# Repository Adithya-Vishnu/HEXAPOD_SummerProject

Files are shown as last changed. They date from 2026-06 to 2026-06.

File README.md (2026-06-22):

# 🦿 HEXAPOD — IITK Robotics Club Summer Project 2025








A from-scratch **18-DOF, six-legged walking robot** — custom CAD, inverse/forward kinematics, Euler-Lagrange dynamics, gait generation, and a Teensy 4.1-driven control stack, built end-to-end over Summer 2025 under the **Robotics Club, IIT Kanpur**.

<p align="center">
  <i>Six legs · three joints each · one base · zero off-the-shelf kits.</i>
</p>

---

## 📌 Overview

Hexapod robots trade the simplicity of wheels for the ability to walk over rubble, gaps, and uneven ground — at the cost of having to solve 18 coupled joint angles in real time just to take a step. This project builds that stack from the ground up:

- **Mechanical** — a hexagonal, circularly-symmetric chassis with slide-in, swappable legs
- **Kinematics** — closed-form inverse kinematics per leg, derived and verified in Python
- **Dynamics** — joint torques derived symbolically via the Euler-Lagrange method (SymPy)
- **Control** — three control-architecture iterations, ending on a single Teensy 4.1 driving all 18 servos directly
- **Locomotion** — wave, ripple, and tripod gaits, simulated in MATLAB before deployment
- **Interface** — manual RC joystick control mapped to omnidirectional leg-sector navigation

Full technical writeup: **[`Hexapod_Documentation.pdf`](./Hexapod_Documentation.pdf)** · Final review deck: **[`End-Eval_Presentation.pdf`](./End-Eval_Presentation.pdf)**

---

## ✨ Highlights

| | |
|---|---|
| **Degrees of Freedom** | 18 (6 legs × 3 DOF: coxa / femur / tibia) |
| **Base** | Hexagonal, legs at edge-midpoints for max clearance + load symmetry |
| **Leg joints** | Dual-bearing supported, slide-lock mounted, fully swappable |
| **Actuation** | 18 × DS5160 60 kg·cm metal-gear digital servos |
| **Controller** | Teensy 4.1 (600 MHz ARM Cortex-M7) — direct PWM, no multiplexing |
| **Power** | 2S1P 7.4V LiPo, 3300 mAh, 25C, XT60 |
| **Gaits** | Wave · Ripple · Tripod — all simulated in MATLAB |
| **Control input** | FlySky FS-i6 RC transmitter, atan2-based 6-sector direction mapping |

---

## 📂 Repository Structure

```
HEXAPOD_SummerProject/
├── CAD_Design/              # Fusion 360 source + STEP exports for every part
│   ├── Assembled bot.f3z        — full bot assembly
│   ├── Entire_BODY v4.f3z        — body/base iteration
│   ├── fixed_tibia.f3d           — tibia (cross-braced, lightweight)
│   ├── hexapod_coxa and slidder.step
│   ├── slider mount.step
│   └── Coxa servo motor.SLDPRT / .STEP
│
├── Codes/                   # Firmware, kinematics, and gait code
│   ├── Teensy_code.ino           — single-board 18-servo control (final arch.)
│   ├── 3_GAITS.ino               — wave / ripple / tripod gait state machine
│   ├── hexapod_ik_solution.py    — inverse kinematics solver per leg
│   ├── Forward kinematics.py     — FK verification against IK output
│   ├── Ripple.m.txt              — MATLAB ripple gait simulation
│   └── Code.cpp                  — leg-position / coordinate transform math
│
├── Entry tasks/              # Onboarding tasks completed before the main build
│   (DOF visualizations, early IK attempts, trig derivations)
│
├── Gcodes/                   # Sliced G-code for every 3D-printed part
│
├── timelapse/                 # Build-process videos, print timelapses
│
├── Hexapod_Documentation.pdf   # Full technical report (mechanical + electrical + control)
└── End-Eval_Presentation.pdf   # Final evaluation slide deck
```

---

## 🦾 Mechanical Design

- **Hexagonal base** chosen over circular for the same structural symmetry at lower material cost; legs sit at **edge midpoints** rather than corners for better clearance and base-leg contact area.
- Each leg **slides into the base** through interlocking stepped slots — this maximizes coxa-base contact area (the coxa sees the highest torque in the system) and lets a faulty leg be swapped without touching the rest of the bot.
- The **coxa-femur joint** went through a full redesign cycle: an initial plus-shaped cross-section concentrated stress at multiple points, so it was rebuilt as a solid cuboid with triangular extrusions sandwiched between **dual ball bearings** — countering the single-sided servo shaft and distributing rotational load evenly.
- The **femur** houses both its servos internally with a cross-shaped internal brace to resist bending under load; the **tibia** uses a cross-truss internal lattice to stay light without losing stiffness, with a stepped hinge angle for better load transfer when climbing.

---

## 🧮 Kinematics & Dynamics

Each leg is modeled as a 3-DOF serial manipulator (coxa → femur → tibia). Given a target foot position `(x, y, z)`, the inverse kinematics solves for joint angles:

```
α = atan2(y, x)                         # coxa (yaw)
r = √(x² + y²),  d = √(r² + z²)
γ = acos((a² + b² − d²) / 2ab)          # tibia (knee angle, law of cosines)
β = atan2(z, r) + acos((a² + d² − b²) / 2ad)   # femur (shoulder angle)
```

implemented and verified in [`hexapod_ik_solution.py`](./Codes/hexapod_ik_solution.py) with a forward-kinematics cross-check in [`Forward kinematics.py`](./Codes/Forward%20kinematics.py).

On top of this, joint **torques τ₁, τ₂, τ₃** were derived symbolically with the **Euler-Lagrange method** (kinetic + potential energy of the 3-link leg, differentiated via SymPy) — used to size the actuators and sanity-check the DS5160's torque margin under worst-case moment arm.

---

## ⚡ Control System Evolution

The control architecture went through three iterations before settling on the final design — each one solving a real failure mode of the last:

| # | Architecture | Why tried | Why dropped |
|---|---|---|---|
| 1 | Arduino Mega 2560 + dual PCA9685 | 32 PWM channels over I²C, minimal wiring | PCA9685 capped at 6V servo rail; bypassing it for 7.4V caused PWM cross-talk / erratic signals |
| 2 | Dual Arduino Mega 2560 (master-slave) | Splits 18-servo IK load across two boards | Sync drift between boards, wiring complexity, 8-bit clock ceiling for real-time IK |
| 3 | **Teensy 4.1** ✅ | 600 MHz Cortex-M7, 20+ PWM-capable pins | — final architecture, drives all 18 servos directly at 1 kHz |

**Actuators:** 18 × DS5160 servos (60 kg·cm @ 7.4V, full metal gear, dual ball bearing, ~0.16 s/60°)
**Power:** 7.4V–8.4V 2S1P LiPo, 3300 mAh, 25C continuous discharge, fused per rail
**Manual control:** FlySky FS-i6 + FS-iA6B receiver — joystick X/Y read as PWM pulse widths, converted to a heading via `atan2`, then mapped into 6 × 60° sectors, each assigned to a "lead leg" for omnidirectional driving without conflicting motion commands.

---

## 🚶 Gait Implementation

| Gait | Legs moving at once | Stability | Speed | Best for |
|---|---|---|---|---|
| **Wave** | 1 | Highest (5 always grounded) | Slowest | Rough/uneven terrain |
| **Ripple** | 1 (overlapping) | High | Moderate | Mixed terrain |
| **Tripod** | 3 | Good | Fastest | Flat ground — default gait |

All three were modeled and animated in MATLAB ([`Ripple.m.txt`](./Codes/Ripple.m.txt) and equivalents for wave/tripod) before being ported to the firmware gait state machine in [`3_GAITS.ino`](./Codes/3_GAITS.ino).

---

## 🚀 Getting Started

**Run the IK/FK solvers (Python):**
```bash
pip install numpy
python "Codes/hexapod_ik_solution.py"
python "Codes/Forward kinematics.py"
```

**Flash the firmware:**
1. Open [`Codes/Teensy_code.ino`](./Codes/Teensy_code.ino) in the Arduino IDE
2. Install the **Teensyduino** add-on and the `Servo` library
3. Select **Tools → Board → Teensy 4.1**, connect via USB, and upload
4. For gait testing on the Mega-based setup, use [`3_GAITS.ino`](./Codes/3_GAITS.ino) instead

**3D-print the parts:** sliced files are ready to go in [`Gcodes/`](./Gcodes); source CAD (Fusion 360 `.f3z`/`.f3d` + STEP) is in [`CAD_Design/`](./CAD_Design).

---

## 🔭 Future Work

- Rubber end-effector tips on the tibia for better terrain grip
- Environmental sealing for outdoor/field operation
- Onboard sensor fusion (IMU/distance) for autonomous, terrain-adaptive gait switching
- Migrating from RC manual control to fully autonomous path planning

---

## 👥 Team — Summer Project 2025, Robotics Club IIT Kanpur

**Mentors:** Kishor Kunal · Shivansh Gupta · Vivek Pawar

**Team:** Adithya Vishnu · Arnav Gupta · Ayush Dwivedi · Dibyanshu · Gungun Jain · Harsh Chandwani · Manant · Namya Mayur Jarag · Saket Pratap Singh · Shivam Agrawal · Subhankar Mondal · Suryans Kumar Verma · Swethaa · Vaibhav · Varshini Ridikka · Virendra Kala · Sameer Baranwal · Sandeep Kumar

---

<p align="center"><i>Built leg by leg, bug by bug. 🦿</i></p>

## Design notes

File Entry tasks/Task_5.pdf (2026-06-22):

# Task_5 code explanation

Created | April 13, 2025
Class | Summer Projects SnT

Code Run-through

Function imported - math function is used for the trigonometric functions in the code.

User Defined functions:

check_triangle_existence(a,b,c):

To check the triangle if it is possible to reach or not by using basic properties returning 1 if not possible and 0 if it is possible to reach.

inverse_kinematics(x,y,z)

takes the input of the point to be reached, and prints out the alpha, beta and gamma angles that are specified in the below images with the assumptions.

I have considered 3 DOF’s

Coxa = 5 units , Femur = 10 units , Tibia = 15 units

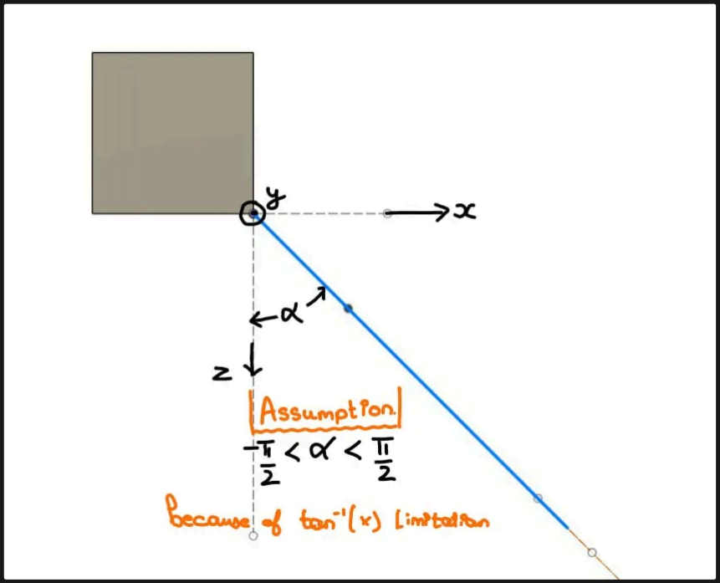
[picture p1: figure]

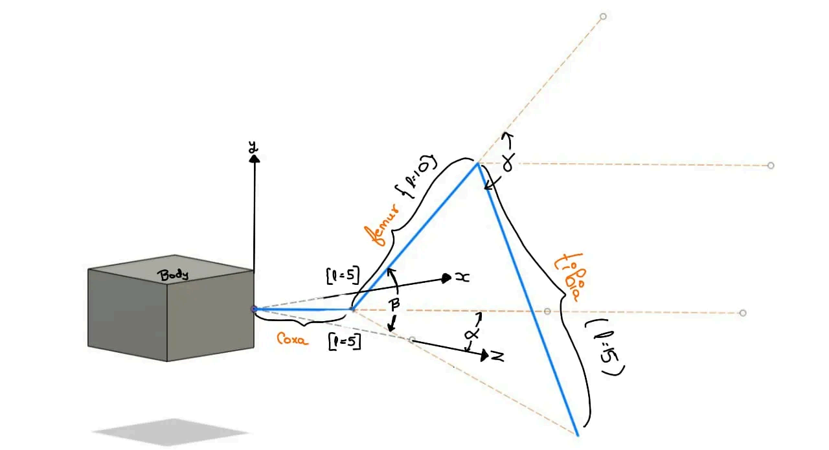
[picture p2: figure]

To find the angle (alpha) we use the tan inverse function. If z==0; it goes out of bounds of the tan inverse function, so we specifically use an if function to output ±(π/2).

we use the round(x,z) function to round x to z decimal points, and round is an inbuilt function in python.

then we find the coordinates of the end of the coxa, to find one side of the triangle that is formed by the femur, tibia and dist.

and beta and gamma is found out using the following formulas:

and if it is possible to reach the output is printed and if it not possible “Sorry not possible to reach” is printed.

test_inverse_kinematics()

tests the cases for 5 tests

TEST 1

typical reachable point {(10.0, 5.0, -10.0)} (since distance to the point is < 25)

TEST 2

very close to base {(1.0, 1.0, -1.0)} (since the distance to this point is <<25)

TEST 3

Near max extension {(5.0, -24.0, 0.0)} (since the distance to this point is ~25)

TEST 4

Unreachable (distance > 25 units) {(20.0, 20.0, -10.0)} (since the distance to this point is >25)

TEST 5

Foot deeply below base {(5.0, -10.0, 0.0)}

### OUTPUT

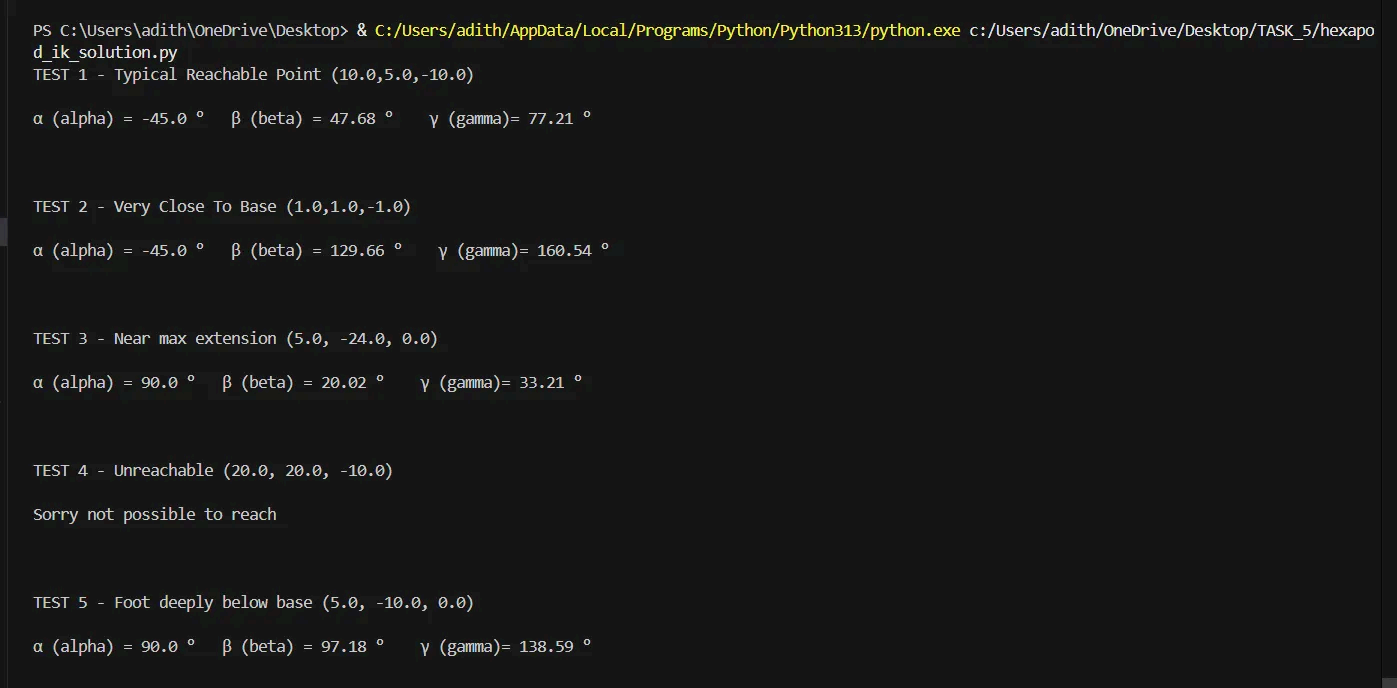
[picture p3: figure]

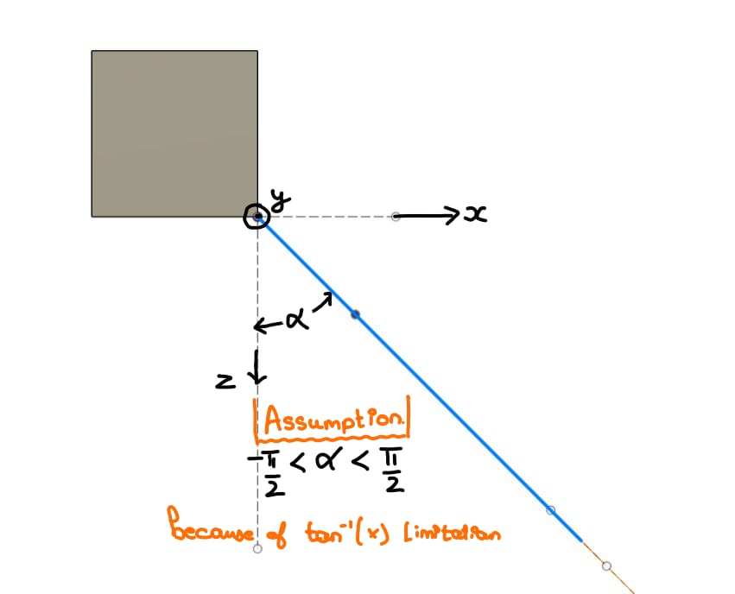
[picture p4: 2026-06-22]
Entry tasks/Top_View.jpg

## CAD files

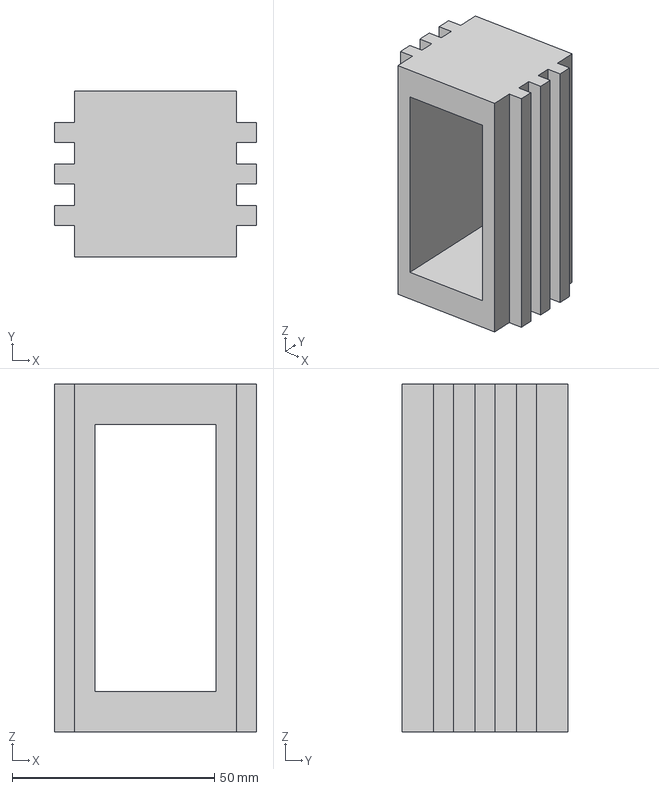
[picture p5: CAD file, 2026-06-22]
CAD_Design/slider mount.step
50.0 x 41.0 x 86.0 mm

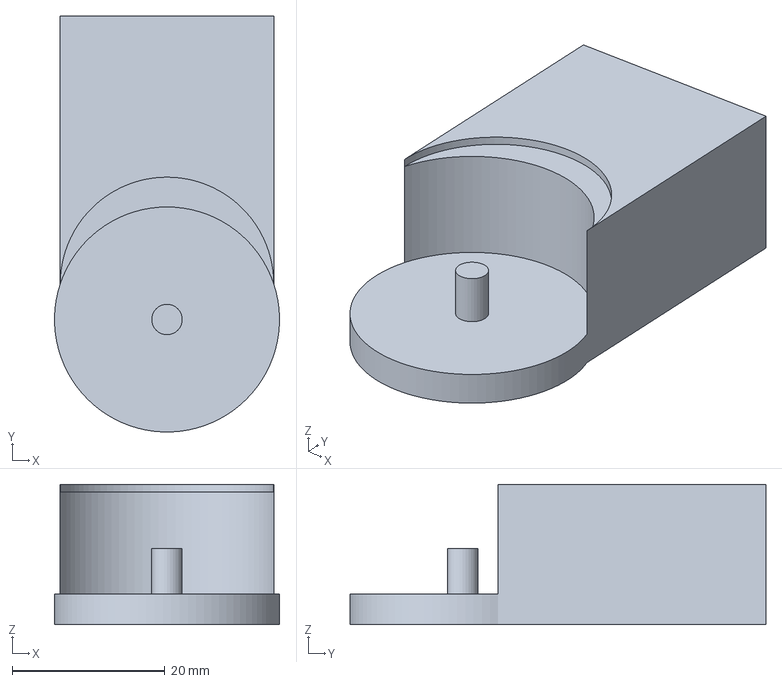
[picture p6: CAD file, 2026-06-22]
Gcodes/3D Printing_Coxa/Upper_mount_holder.3mf
29.5 x 54.5 x 18.4 mm

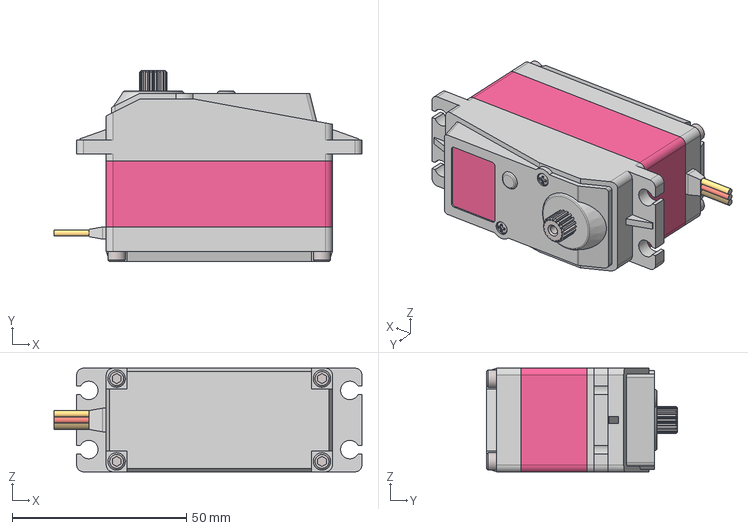
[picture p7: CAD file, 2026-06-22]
CAD_Design/Servo Motor v1.step
88.5 x 55.0 x 29.8 mm

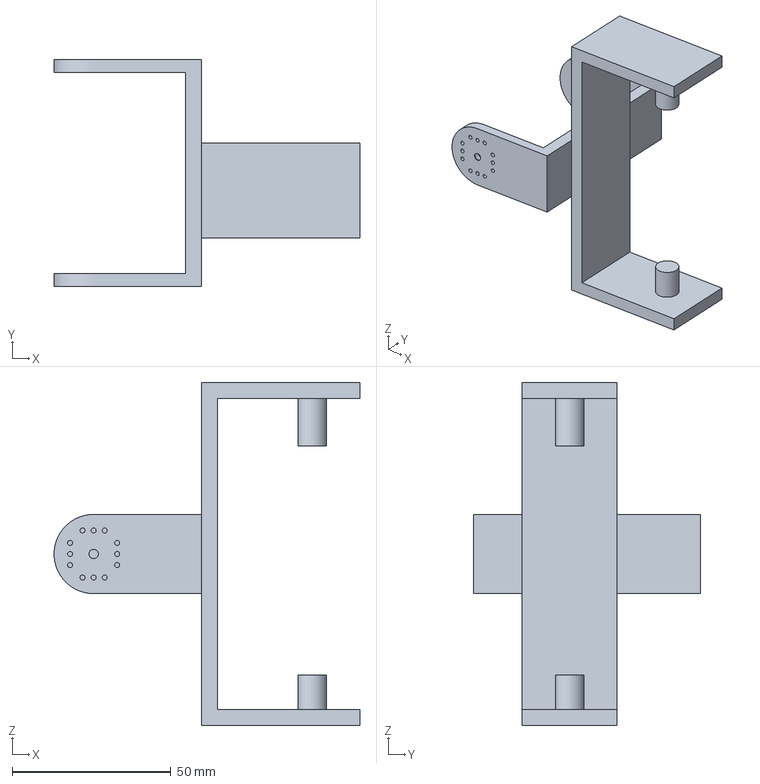
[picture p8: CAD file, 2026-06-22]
Gcodes/3D Printing_Coxa/Coxa_Femur_connection mount.3mf
96.5 x 71.5 x 108.2 mm

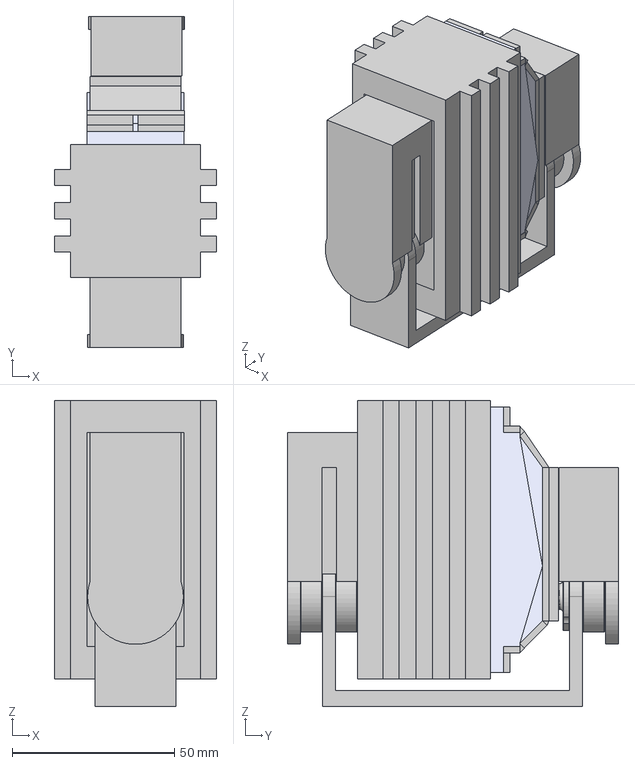
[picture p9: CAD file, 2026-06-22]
CAD_Design/hexapod_coxa and slidder.step
50.0 x 102.1 x 94.5 mm

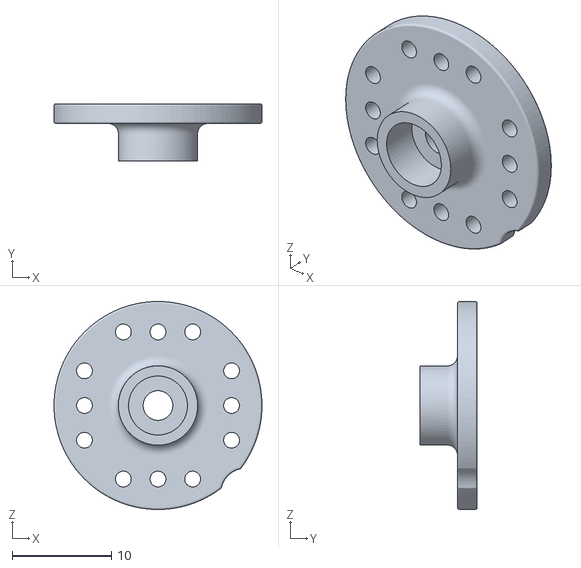
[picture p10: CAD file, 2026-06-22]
Gcodes/3D Printing_Coxa/motor holder.stl
21.0 x 5.80 x 21.0

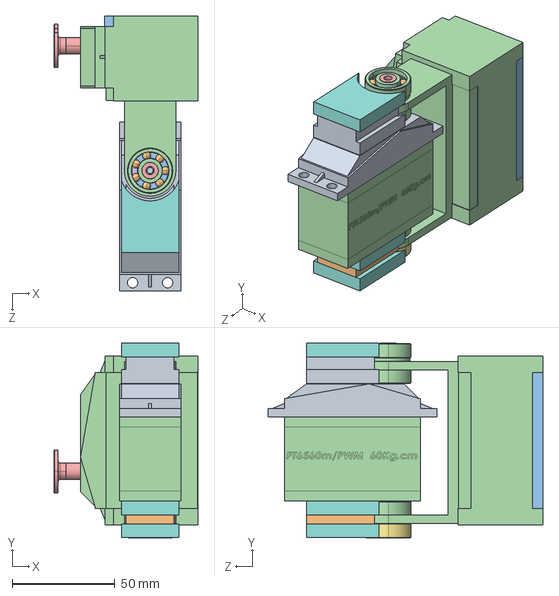
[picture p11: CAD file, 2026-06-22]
CAD_Design/Coxa servo motor.STEP
69.8 x 94.6 x 133.6 mm

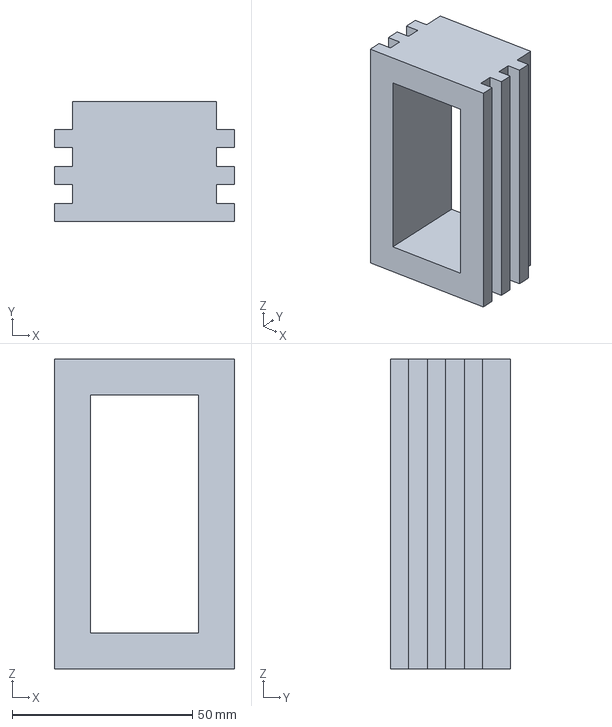
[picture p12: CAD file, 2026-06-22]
Gcodes/3D Printing_Coxa/Motor_slider_mount.3mf
50.0 x 33.2 x 86.0 mm

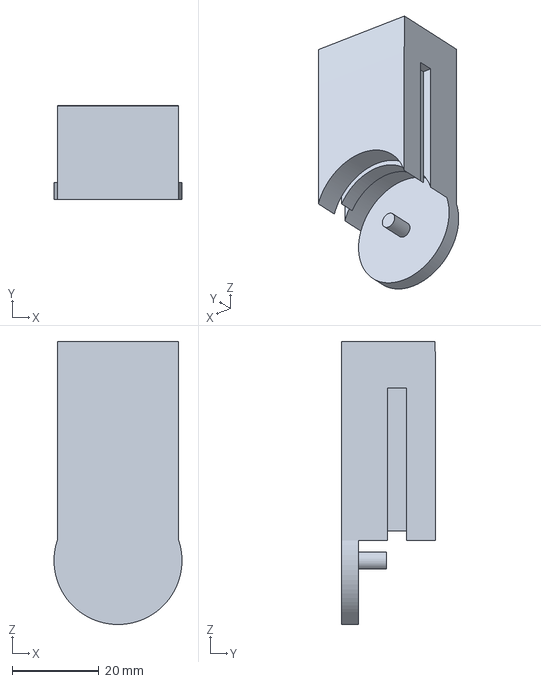
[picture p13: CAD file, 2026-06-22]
Gcodes/3D Printing_Coxa/lower_mount_holder.3mf
29.5 x 21.8 x 65.3 mm

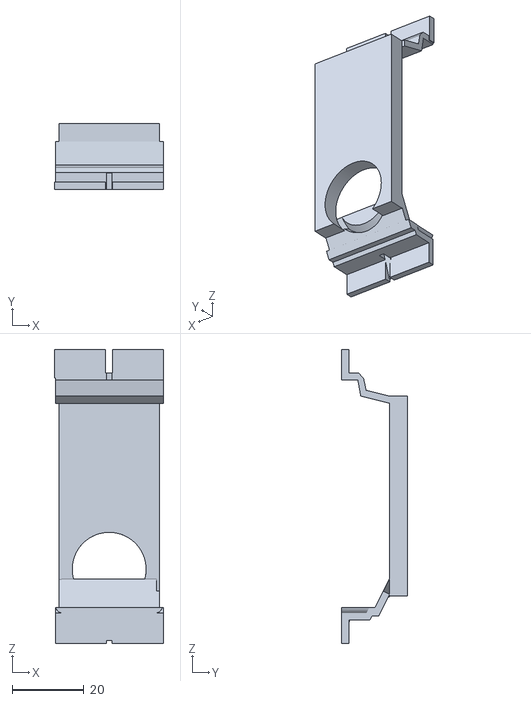
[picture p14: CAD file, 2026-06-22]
Gcodes/3D Printing_Coxa/motor_mount_bracket_fuckuuuu.stl
30.5 x 18.3 x 82.0

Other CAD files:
Gcodes/Final_boss_1.gcode.3mf
Gcodes/part_2.gcode.3mf
Gcodes/final.gcode.3mf
Gcodes/FINALLLLLL_ABSOLUTE.gcode.3mf
Gcodes/part_1.3mf
Gcodes/Final_boss_2.gcode.3mf
Gcodes/Motor_slider_mount.gcode.3mf
CAD_Design/Assembled bot.f3z
CAD_Design/Entire_BODY v4.f3z
CAD_Design/fixed_tibia.f3d
Gcodes/3D Printing_Coxa/lower_mount_holder.stl

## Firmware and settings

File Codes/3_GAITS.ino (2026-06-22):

//master code
#include <Wire.h>
#include <Servo.h>


Servo coxa;
Servo femur;
Servo tibia;

Servo coxa2;
Servo femur2;
Servo tibia2;

Servo coxa3;
Servo femur3;
Servo tibia3;

const int coxa_pin=2;
const int femur_pin=3;
const int tibia_pin =4;
 
const int coxa2_pin=11;
const int femur2_pin=6;
const int tibia2_pin=7;

const int coxa3_pin=8;
const int femur3_pin=9;
const int tibia3_pin=10;
   //variable to store the servo position

double alpha,beta,gamma,alpha2,beta2,gamma2;

const double Angles[21][3] = {{45.0, 140.02, 120.8}, {44.49, 144.5, 123.15}, {43.94, 149.06, 125.37}, {43.35, 153.71, 127.46}, {42.71, 158.42, 129.4}, {42.01, 163.2, 131.21}, {41.22, 168.02, 132.87}, {40.31, 172.89, 134.4}, {39.21, 177.84, 135.81}, {27.4, 179.26, 141.22}, {26.33, 174.61, 140.6}, {25.38, 169.71, 139.66}, {24.51, 164.67, 138.44}, {23.71, 159.54, 136.96}, {22.96, 154.41, 135.25}, {22.26, 149.31, 133.33}, {21.59, 144.28, 131.23}};
const double Angles2[21][3]={{45.0, 140.02, 120.8}, {45.0, 143.85, 121.82}, {45.0, 147.56, 122.59}, {45.0, 162.49, 121.72}, {45.0, 164.3, 120.27}, {45.0, 165.32, 117.99}, {45.0, 162.99, 111.76}, {45.0, 155.41, 105.17}, {45.0, 150.83, 102.15}, {45.0, 146.71, 99.57}, {45.0, 142.82, 97.14}, {45.0, 139.04, 94.74}, {45.0, 135.33, 92.31}, {45.0, 131.65, 89.82}, {45.0, 128.0, 87.23}, {45.0, 124.37, 84.53}, {45.0, 120.72, 81.71}};
const double Angles3[21][3]={{21.59, 112.87, 67.05}, {22.26, 115.66, 68.63}, {22.96, 118.33, 69.99}, {23.71, 120.89, 71.13}, {24.51, 123.33, 72.03}, {25.38, 125.64, 72.71}, {26.33, 127.8, 73.14}, {27.4, 129.79, 73.29}, {39.21, 126.34, 64.81}, {40.31, 123.46, 63.05}, {41.22, 120.57, 61.23}, {42.01, 117.61, 59.28}, {42.71, 114.6, 57.15}, {43.35, 111.49, 54.83}, {43.94, 108.26, 52.27}, {44.49, 104.91, 49.43}, {45.0, 101.39, 46.26}};
void setup(){
  Serial.begin(9600);
  Wire.begin();
  coxa.attach(coxa_pin);
  femur.attach(femur_pin);
  tibia.attach(tibia_pin);

  coxa2.attach(coxa2_pin);
  femur2.attach(femur2_pin);
  tibia2.attach(tibia2_pin);

  coxa3.attach(coxa3_pin);
  femur3.attach(femur3_pin);
  tibia3.attach(tibia3_pin);
}
void loop() {
  Serial.println("At start of loop");
  for(int i=0;i<17;i=i+1){
    // alpha=Angles[i][0];
    // beta=Angles[i][1];
    // gamma=Angles[i][2];

    // alpha2=Angles2[i][0];
    // beta2=Angles2[i][1];
    // gamma2=Angles2[i][2];

    coxa.write(180-2*(Angles[i][0]));
    coxa2.write(180-2*(Angles3[i][0]));
    coxa3.write(180-2*(Angles2[i][0]));
    delay(20);

    femur.write(Angles[i][1]);
    femur2.write(Angles3[i][1]);
    femur3.write(Angles2[i][1]);
    delay(20);

    tibia.write(Angles[i][2]);
    tibia2.write(Angles3[i][2]);
    tibia3.write(Angles2[i][2]);
    delay(20);
    

  }
  Serial.println("End of loop");
  Wire.beginTransmission(8);
  Wire.write(1);
  delay(20000);
  Wire.endTransmission();
  
  Wire.beginTransmission(8);
  Wire.write(0);
  Wire.endTransmission();
}
